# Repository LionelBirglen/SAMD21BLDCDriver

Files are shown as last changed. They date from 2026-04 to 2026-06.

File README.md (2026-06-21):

# SAMD21 BLDC Driver for the IFlight GM3506 and GM4108 Motors

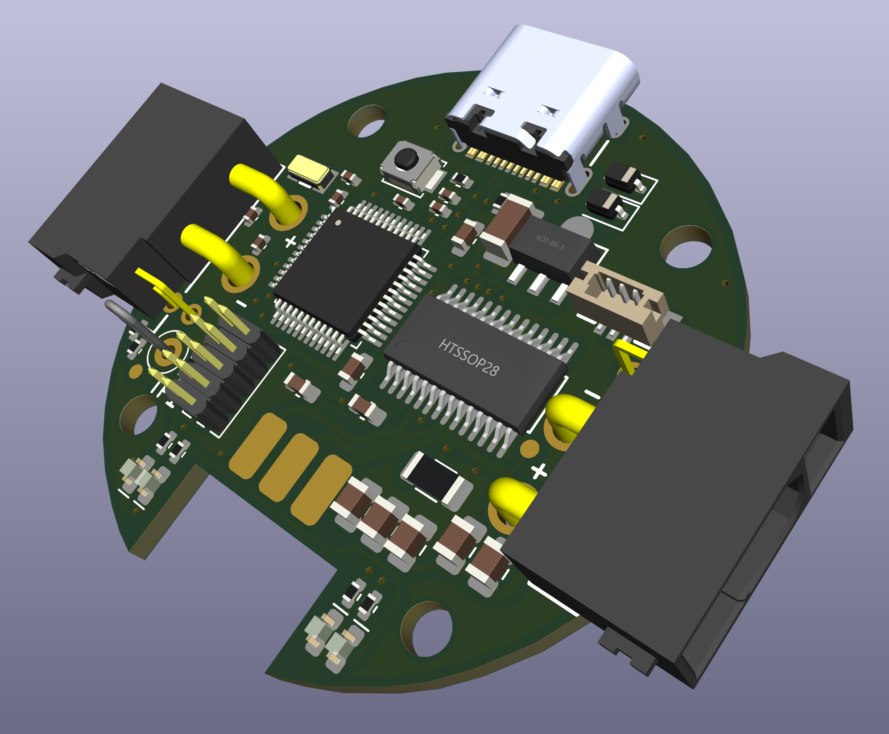
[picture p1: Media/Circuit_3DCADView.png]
Driver


Brushless motor driver board based on a SAMD21 microcontroller and DRV8313 driver with a form factor fitting the IFlight GM3506 Motor. Driver specifications are also compatible with the GM4108 motor and an enclosure for the latter is provided.

## Overview

This driver is inspired by a great project from Jordan Cormack: <https://cormack.xyz/L433motordriver/> but with no source provided (yet?), I decided to share here my own version of this board. Being far more familiar with the SAMD21 microcontroller, I used that one instead of the STM32 in Dr. Cormack's design. The board has only two electrical layers so it is *extremely* cheap to manufacture. I am using lines PA08 and PA09 for communication which correspond to the I2C port instead of a CAN bus. Therefore, these lines are simpler to use but careful, a big drawback is that it means that **these pins are now only 3.3V tolerant**. Two 10k pullup resistors are integrated to these input lines for convenience and can be relied upon to set the voltage reference if the board is controlled from an open collector output. The drives have two identical input/ouput connectors and thus, can be daisy chained.

## XIAO Compatibility & Programming

The whole board is pin for pin compatible with the Seeeduino XIAO SAMD21 embodiment (<https://wiki.seeedstudio.com/Seeeduino-XIAO/>) so you can use their firmware to flash the board and then, program it using the USB-C port as if it was a XIAO. The input lines then become D4 and D5 for you to use as you like (I2C or GPIO). See: <https://emalliab.wordpress.com/2023/03/12/unbricking-a-seeed-xiao-samd21/> for instructions on how to flash the board through the available SWDIO 2x5 connector whose **key pin is indicated by the K letter on the silkscreen**. Programming through the SWDIO connector is also possible of course. In the following, Seeedstudio equivalent lines are indicated betweeen parentheses.

## Power & Daisy-Chaining

Controllers can be daisy chained and approx. 8A can be passed from one board to the next based on a temperature estimation by software so up to 8 GM3506 motors could be connected in series using the 1A maximal current recommended by IFlight for GM3506s. Maximal input voltage on the XT30 power lines is 25V. Maximal output current per board is around 2-2.5A, depending on cooling and ambient temperature.

There is an available connector on the board that is compatible with the BSB0203HA3-00CER 20mm fan (Digikey ref. 603-2068-ND) but after experimenting with the latter I noticed its cooling power is frankly quite limited and if you block its fins by accident the current drawn will shoot up which causes a brownout of the SAMD21. So I cannot advice using this fan and removed the files of the 3D printed enclosure I made which included a place to attach this fan. Alternatively, this connector could be used to power additional components, there are three lines available on the BM03B-SURS-TF connector: GND, NC, and 3.3V.

## Pinout

**DRV8313 power driver control:**

| Function | SAMD21 Pin | XIAO Equivalent |
|---|---|---|
| Enable | PA02 | D0 |
| PWM1 | PB08 | D6 |
| PWM2 | PA04 | D1 |
| PWM3 | PB09 | D7 |

No feedback from the DRV8313 is read due to routing complexity with only two layers. Low side total current sensing is available through a 0.1 ohm power resistor connected to the PA10 line (A2).

**AS5048A encoder (mounted on the backside, center of the board, connected via SPI):**

| Function | SAMD21 Pin | XIAO Equivalent |
|---|---|---|
| MISO | PA05 | D9 |
| MOSI | PA06 | D10 |
| CLK | PA07 | D8 |
| SS | PA11 | D3 |

The decoupling capacitors close to that chip are recommended but can be left unpopulated without issues from my experiments due to the very close quite large bank of bulk capacitors located on the other side of the board.

## LEDs & Power Source

There are four LEDs located besides the motor soldering pads, the red one indicates that 3.3V power is active. The other three are available to the user, if you use the Seeestudio firmware, one will blink during serial communication (green) and the other two (orange) are connected to the Rx/Tx lines.

Powering the board with 3.3V is done through either the USB-C lines or the XT30 power connector. Switching from one power source to the other is automatic since both lines are OR-ed and protected with 1N5819WS diodes. Maximal input voltage is 25V. **Careful there is no reverse polarity or overcurrent protection on the input, swapping the XT30 lines will destroy the board!**

## Software and Enclosures

For actual control of the motor, the SimpleFOC library works very well and is recommended, see: <https://simplefoc.com/>. CAD files of a 3D printed enclosure for both the GM3506 and GM4108 motors are also provided in this repository.

## Repository Contents

- `Circuit/`: interactive html BOM with component location and 3D step model of the populated board
- `Enclosures/`: files for 3D printing a proposed enclosure for the GM3506 and GM4108 motors and board
- `Gerber/`: zip file with the gerber and drill files for manufacturing. PCA files are also provided if factory assembly is desired: bom and verified component location files (see note below)
- `Media/`: general pics and videos

Note: since only the AS5048A is on the backside, manual soldering of the latter is assumed. Single face PCBA costs significantly less so almost all components were placed on the front. Only the AS5048A needs to be soldered on the back.

## Pictures

Pictures of fully assembled boards:

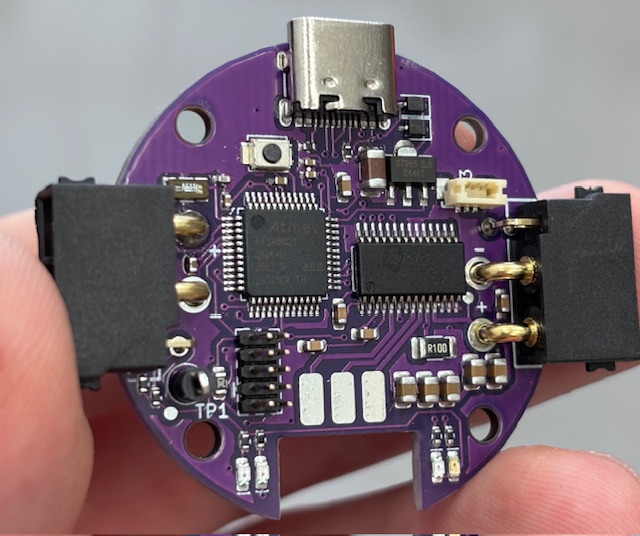
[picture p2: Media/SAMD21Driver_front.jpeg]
pcb front
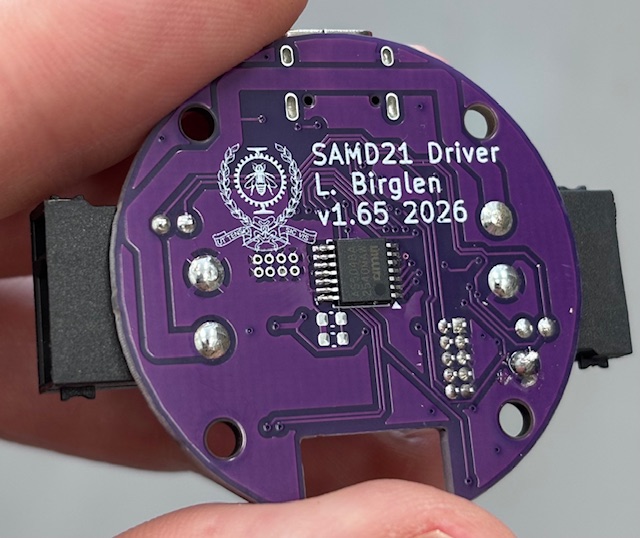
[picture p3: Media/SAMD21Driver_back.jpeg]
pcb back
 

## Video

Demo

Demonstration of the position control of two GM3506 motors in series using SimpleFOC. When the white button is pressed, left motor turns 180 degrees while the right one makes a full turn. Measured response time is around 180 ms.

## Version History

- v1.65: initial release
- v1.66: pullup resistors changed to 10k (better when multiple drives are daisy chained), trimmed sharp pcb edges, minor adjustments to silkscreen

## DISCLAIMER

This hardware project is provided "as is", and at your own risk. Under no circumstances shall any author be liable for direct, indirect, special, incidental, or consequential damages resulting from the use, misuse, or inability to use this hardware/software, even if the authors have been advised of the possibility of such damages.

---

Prof. Lionel Birglen<br/>
Polytechnique Montreal, 2026<br/>
License: GNU GPL v3

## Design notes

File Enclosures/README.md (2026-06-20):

## Enclosures to 3D print for the driver and GM3506/4108 motors

### GM3506:
- Print one of each of SAMD21_GM3506_xxx.stl files<br/>
- Assemble with 4 M2.5x12-14 (pcb to motor+ring+cap) and 4 M2x25 flat head (previous assembly to tube) screws<br/>
- See SAMD21_GM3506_assembly.png for a picture.

### GM4108:
- Print one of each of SAMD21_GM4108_xxx.stl files<br/>
- Assemble with 4 M3x8 (pcb to motor+ring), 4 M2.5x12 (previous assembly to cap), and 4 M3x8-20 flat head (previous assembly to tube) screws<br/>
- Notice that there is a 15 degree shift between the pcb and ring part. This is required because the threaded holes on the GM3506 and GM4108 motors are different. So to use the same pcb for both motors, the latter needs to be slightly rotated.<br/>
- See SAMD21_GM4108_assembly.png for a picture.

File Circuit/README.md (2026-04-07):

Open the html file with the navigator of your choice for an interactive BOM listing all components of the board as well as their layout. Second file here is the 3D model of a fully assembled board.

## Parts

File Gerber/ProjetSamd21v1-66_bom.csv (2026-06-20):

Designator | Footprint | Quantity | Value | LCSC Part #
C1, C18 | 0402 | 2 | 1uF | C52923
C10, C14, C15, C16, C17 | 0805 | 5 | 22uF | C45783
C11 | 0603 | 1 | 10nF | C57112
C12, C13, C9 | 0603 | 3 | 0.1uF | C14663
C19 | 0603 | 1 | 10uF | C52923
C2, C4, C5 | 0402 | 3 | 0.1uF | C1525
C20 | 0603 | 1 | 0.1uF | C1525
C3 | 1206 | 1 | 10uF
C6 | 0603 | 1 | 10uF | C19702
C7, C8 | 0402 | 2 | 12pF | C1547
CN1 | CONN-SMD_BM03B-SURS-TF | 1 | BM03B-SURS-TF(LF)(SN) | C594379
D1, D2 | 0603 | 2 | LED | C7496820
D3 | 0603 | 1 | LED | C2962098
D4 | 0603 | 1 | LED | C7496811
D5, D6 | D_SOD-323 | 2 | 1N5819WS | C191023
J1 | USB-C_16 | 1 | USB_C_Receptacle | C2765186
J2 | 2x05_P1.27mm | 1 | SWD | C7501289
R1 | 1206 | 1 | 0.1 | C382273
R11, R12 | 0402 | 2 | 3.3k | C25890
R2 | 0603 | 1 | 10k | C25804
R3, R4 | 0402 | 2 | 5.1k | C25905
R5, R6, R7 | 0402 | 3 | 330 | C25104
R9 | 0402 | 1 | 470 | C25117
SW1 | SW_SPST_B3U-1000P | 1 | SW_SPST | C49234121
TP1 | TestPoint_Loop_D2.50mm_Drill1.0mm | 1 | TestPoint
U1 | TSSOP-14_4.4x5mm_P0.65mm | 1 | AS5048A | C2655181
U3 | SOT-89-3_L4.5-W2.5-P1.50-LS4.2-BR | 1 | SE8633K2-HF | C496614
U4 | TQFP-48_7x7mm_P0.5mm | 1 | ATSAMD21G18A-A | C78624
U5, U6 | CONN-TH_4P-XT30PW-M | 2 | XT30(2+2)PW-M.G.B | C19268030
U7 | HTSSOP-28_L9.8-W4.5-P0.65-LS6.6-BL-EP | 1 | DRV8313PWP | C92482
Y2 | Crystal_SMD_3.2x1.5mm | 1 | 32.768kHz | C32346

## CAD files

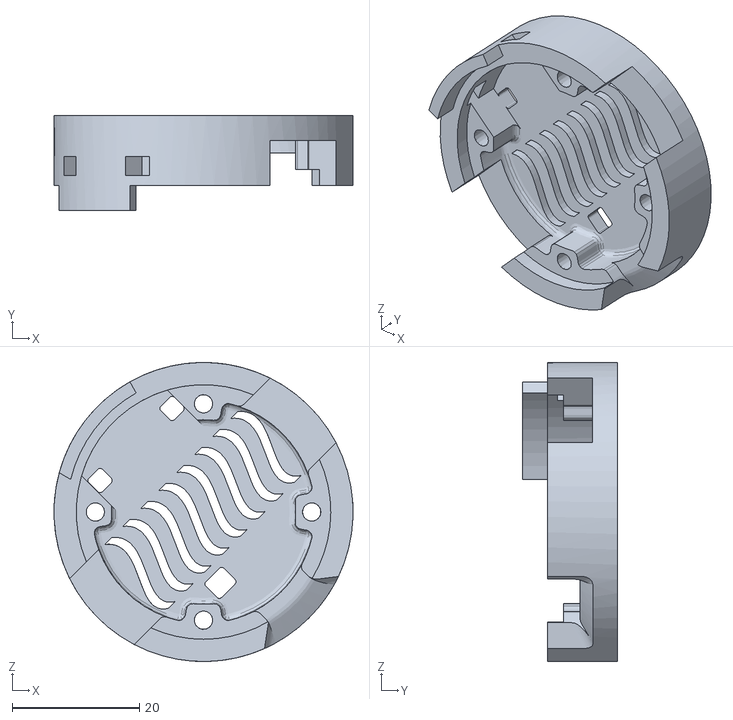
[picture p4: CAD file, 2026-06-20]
Enclosures/SAMD21Driver_GM4108_cap.stl
47.0 x 15.0 x 47.0

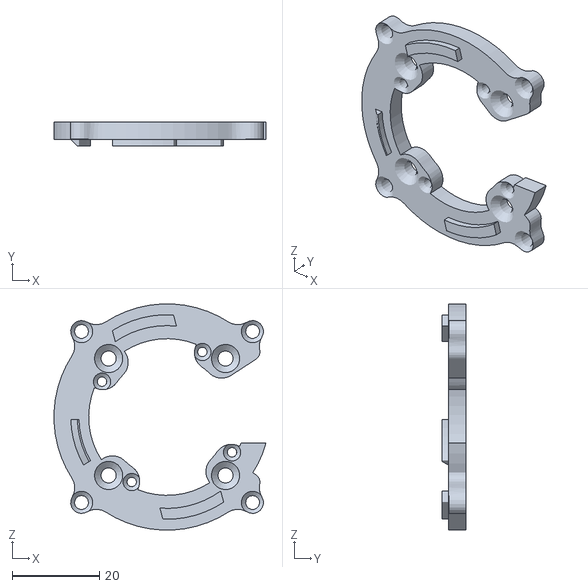
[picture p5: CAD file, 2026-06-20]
Enclosures/SAMD21Driver_GM4108_ring.stl
48.7 x 5.50 x 51.9

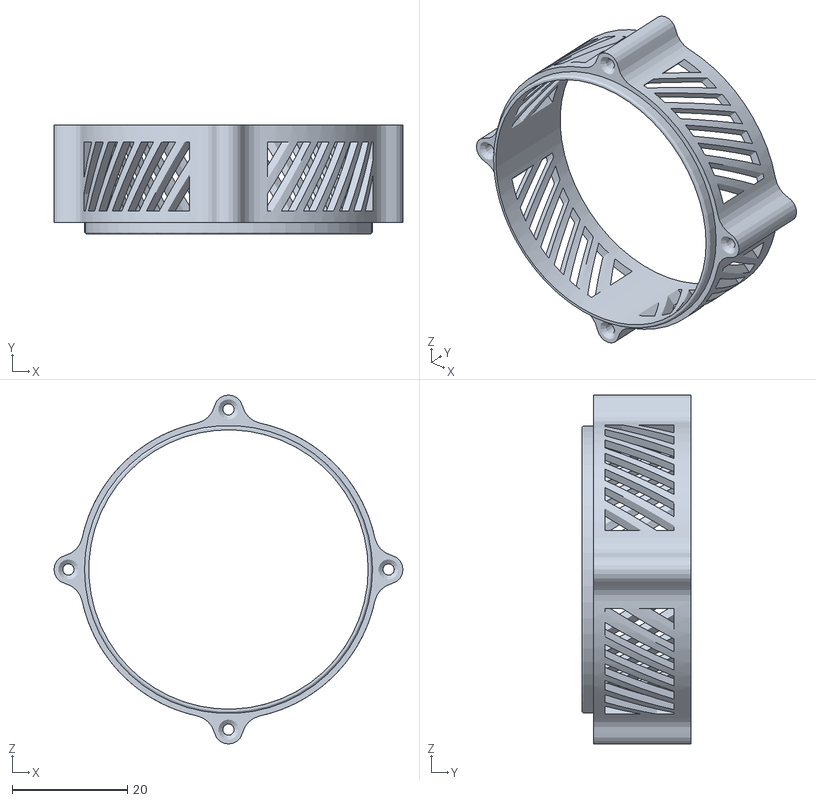
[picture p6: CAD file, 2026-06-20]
Enclosures/SAMD21Driver_GM4108_tube.stl
60.6 x 19.0 x 60.6

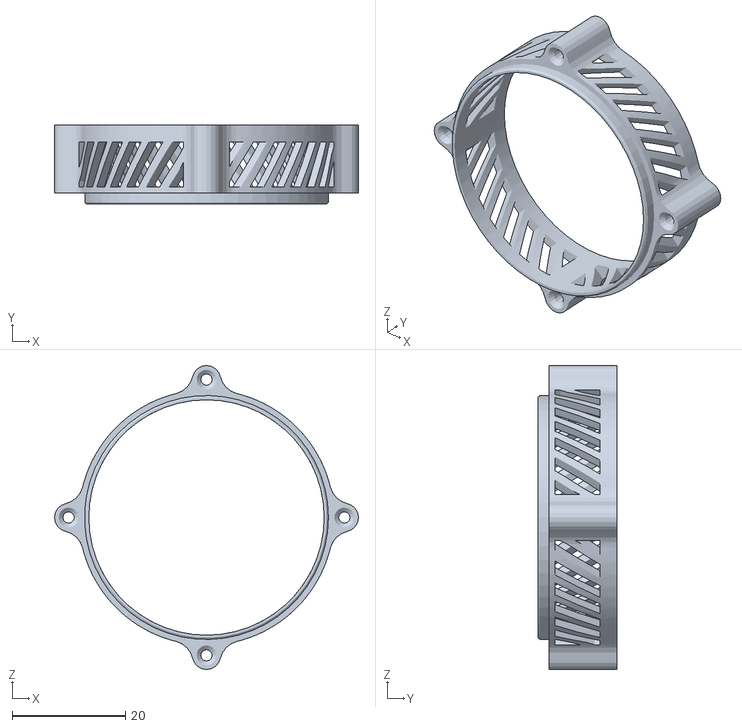
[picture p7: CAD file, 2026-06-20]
Enclosures/SAMD21Driver_GM3506_tube.stl
53.6 x 14.0 x 53.6

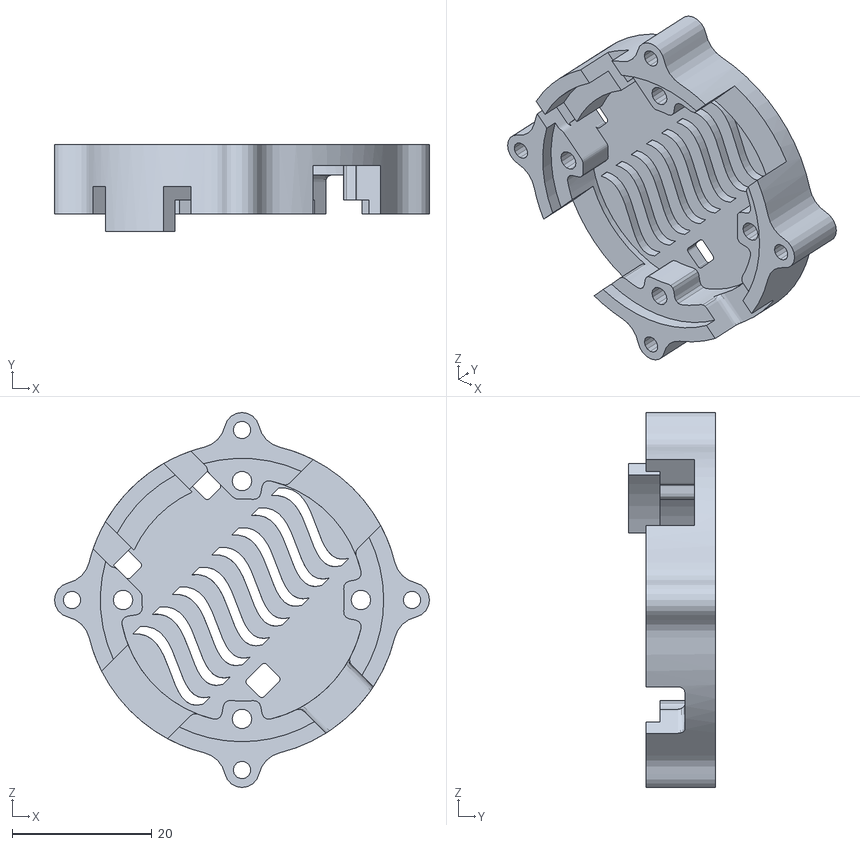
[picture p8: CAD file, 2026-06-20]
Enclosures/SAMD21Driver_GM3506_cap.stl
53.6 x 12.5 x 53.6

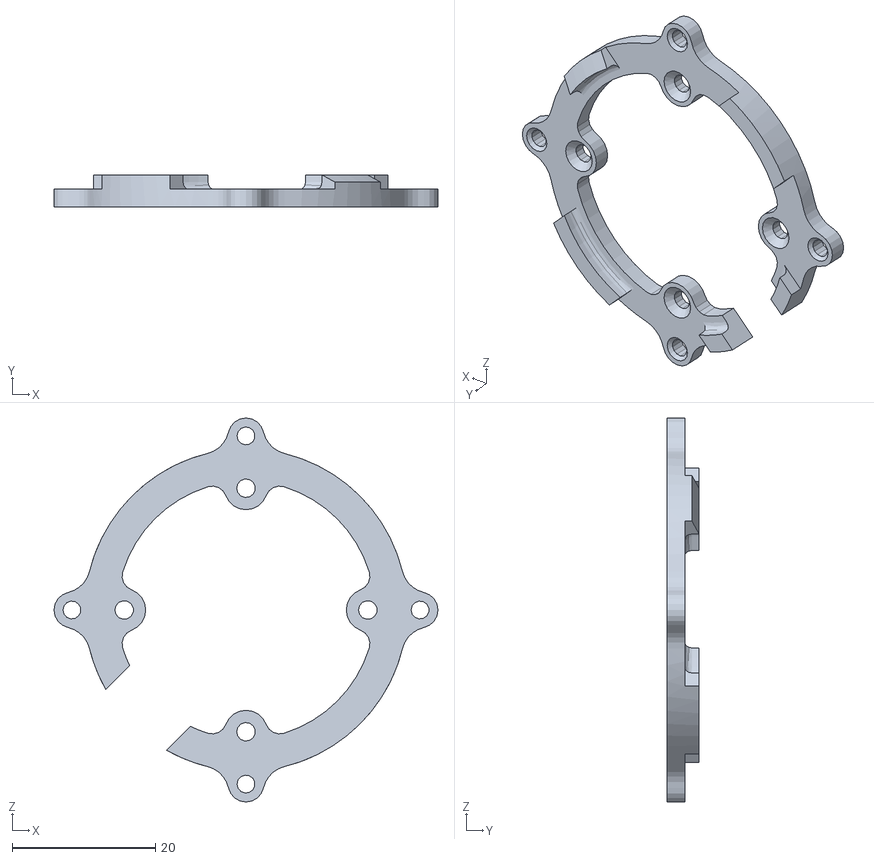
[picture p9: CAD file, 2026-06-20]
Enclosures/SAMD21Driver_GM3506_ring.stl
53.6 x 4.50 x 53.6

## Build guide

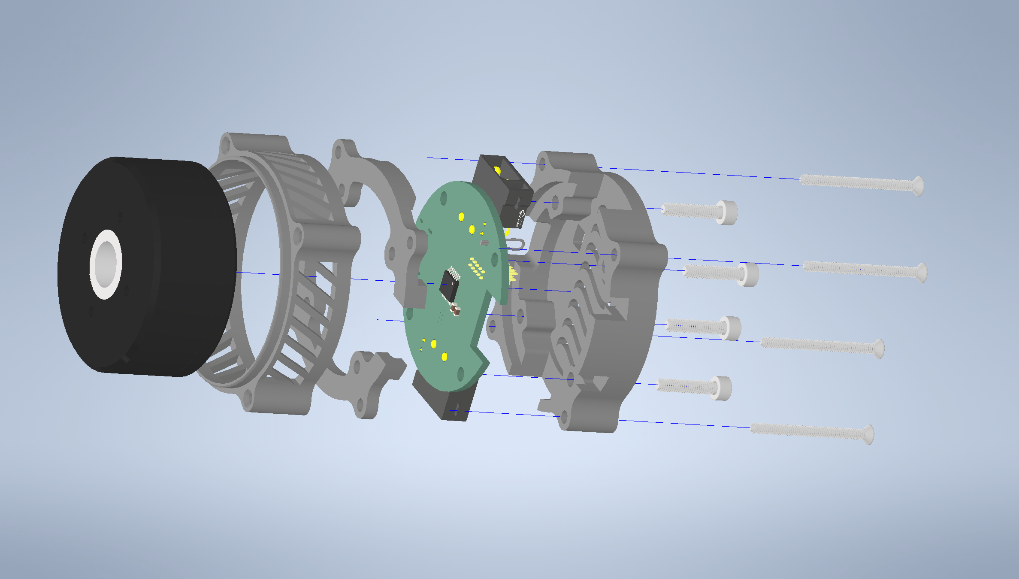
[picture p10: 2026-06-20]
Enclosures/SAMD21Driver_GM3506_assembly.png

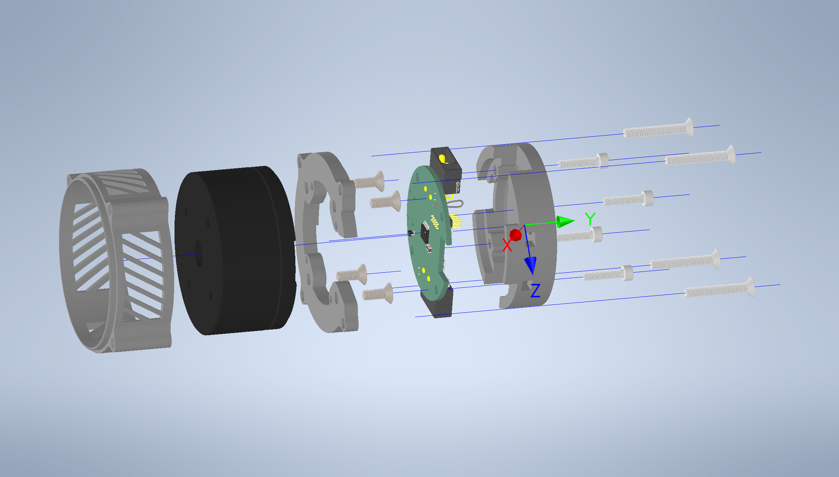
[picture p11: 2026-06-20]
Enclosures/SAMD21Driver_GM4108_assembly.png

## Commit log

2026-04-07 Added gerber files
    [ProjetSamd21v1-65_bom.csv, ProjetSamd21v1-65edited_positions.csv]
2026-04-07 Fix image link in README.md
    Updated image link in README to point to the correct circuit image.
2026-04-07 Update README with I2C details and pin tolerances
    Clarified the use of I2C for input lines and updated details about pin tolerances and resistor integration.
2026-04-07 Update README with additional board details
    Added information about the board's manufacturing cost, cooling options, and recommended library for motor control.
2026-04-07 Revise README for GM3506 motor compatibility
    Updated project title and description to specify compatibility with GM3506 motor and clarified input line changes.
2026-04-07 Revise demo explanation in README
    Updated demo description for motor control behavior.
2026-04-08 Revise README for clarity and detail
    Updated README to clarify communication lines and power specifications. Improved descriptions of board features and components.
2026-04-08 Revise README for clarity on driver board specifications
    Updated the README to clarify the driver board's features and limitations.
2026-04-08 Clarify daisy chaining and power specs in README
    Updated the README to clarify the daisy chaining capability and power specifications for the controllers.
2026-04-08 Update README to remove fan enclosure references
    Removed references to 3D printed enclosure files and clarified the fan's limitations in the README.
2026-04-08 Clarify control lines and power options in README
    Updated the README.md to clarify the control lines for the DRV8313 power driver and added details about the AS5048A encoder chip and power options.
2026-04-13 Update README with assembly pictures and demo video
    Added images and video demonstration of the assembled boards.
2026-04-13 Fix image formatting for SAMD21 Driver pictures
    Updated image tags for the SAMD21 Driver in the README.
2026-04-14 Corrected max input voltage
    Corrected max input voltage
2026-06-20 Upload of v1.66 gerber files
    [ProjetSamd21v1-66_bom.csv, ProjetSamd21v1-66edited_positions.csv]
2026-06-20 Update README with GM3506 assembly instructions
    Added assembly instructions and details for GM3506 motor.
2026-06-20 Update README for enclosure instructions and formatting
2026-06-20 Enhance README with GM4108 and additional details
    Updated the README to include information for the GM4108 motor, added sections for overview, XIAO compatibility, power, pinout, LEDs, software, and repository contents.
2026-06-20 Update motor description in README
2026-06-20 Change PCB image width to 400 pixels
    Updated image dimensions for PCB pictures in README.
2026-06-20 Update README for GM3506/4108 motor enclosures
2026-06-20 Remove duplicate assembly instructions for motors
